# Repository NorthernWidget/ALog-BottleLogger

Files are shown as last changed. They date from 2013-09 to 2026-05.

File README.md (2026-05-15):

ALog-BottleLogger
=================

## Deprecation / update notice

The lovely ALog has a dear place in our hearts, but time flows by.

For our modern supported data loggers, see:
* [Project Margay](https://github.com/NorthernWidget-Skunkworks/Project-Margay): Small form factor ALog-like data logger, optimized for digital communications
* [Project Resnik](https://github.com/NorthernWidget-Skunkworks/Project-Resnik): Data logger for large installations, solar power, and telemetry

## ALog BottleLogger Basic Information

The ALog BottleLogger is an Arduino-based low-power field environmental data logging platform.

This repository contains hardware design files, centered around:
* Electronic schematics
* Circuit board layouts

In addition, the following are supplied, but are not always kept up-to-date in the main branch:
* Bill of materials (electronic components)
* Gerber files for circuit board production
* Pick-and-place files

## Layout Overview for End-Users

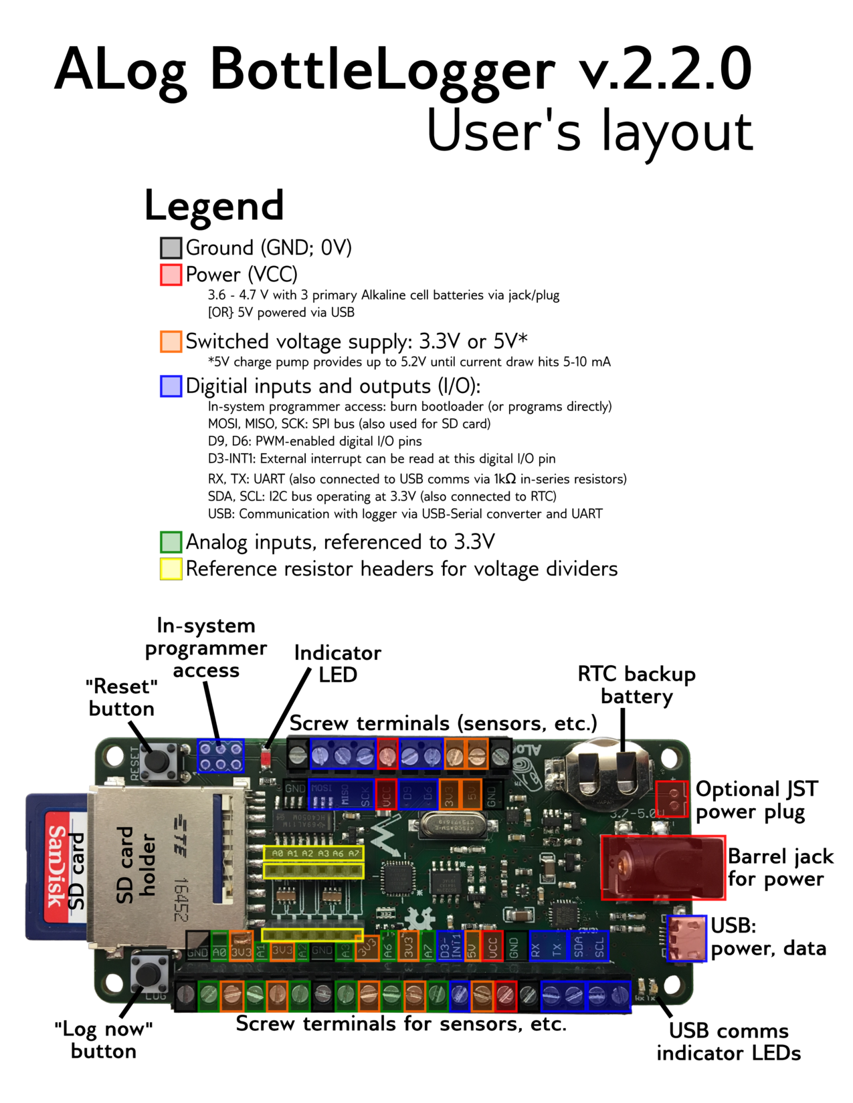
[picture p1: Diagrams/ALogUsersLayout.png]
Layout guide for end-users


<!--
![Major components](https://github.com/NorthernWidget/ALog-BottleLogger/blob/master/Diagrams/ALogComponents.png?raw=true)

## Significant components

<img alt="Major components" src="https://github.com/NorthernWidget/ALog-BottleLogger/blob/master/Diagrams/ALogComponents.png?raw=true" width="1000">

<img alt="Layout guide for end-users" src="https://github.com/NorthernWidget/ALog-BottleLogger/blob/master/Diagrams/ALogUsersLayout.png?raw=true" width="1000">
-->

## Citation

If you use this data logger in a publication, please cite:

**Wickert, A. D. (2014), [The ALog: Inexpensive, Open-Source, Automated Data Collection in the Field](https://doi.org/10.1890/0012-9623-95.2.68), *Bull. Ecol. Soc. Am.*, *95*(2), 68–78, doi:10.1890/0012-9623-95.2.68.**

**Wickert, A. D., C. T. Sandell, B. Schulz, and G.-H. C. Ng (2019), [Open-source Arduino-compatible data loggers designed for field research](https://doi.org/10.5194/hess-23-2065-2019), *Hydrol. Earth Syst. Sci.*, *23*, 2065–2076, doi:10.5194/hess-23-2065-2019.**

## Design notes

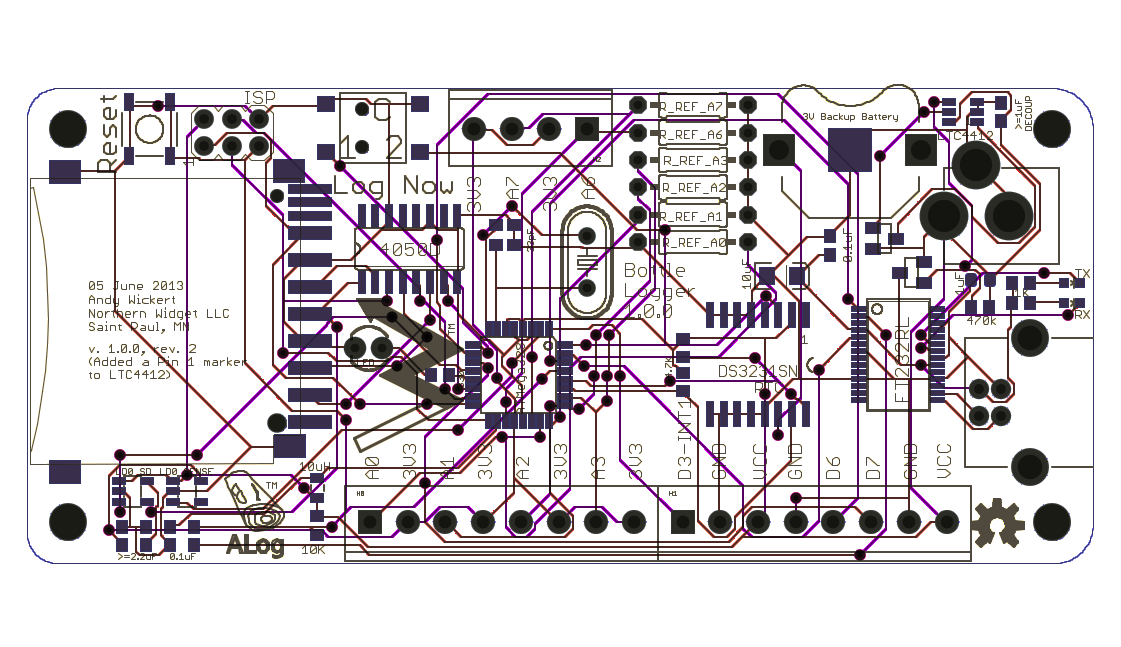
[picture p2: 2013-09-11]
Diagrams/Logger100/ALog_BottleLogger_100_rev2_white_background.png

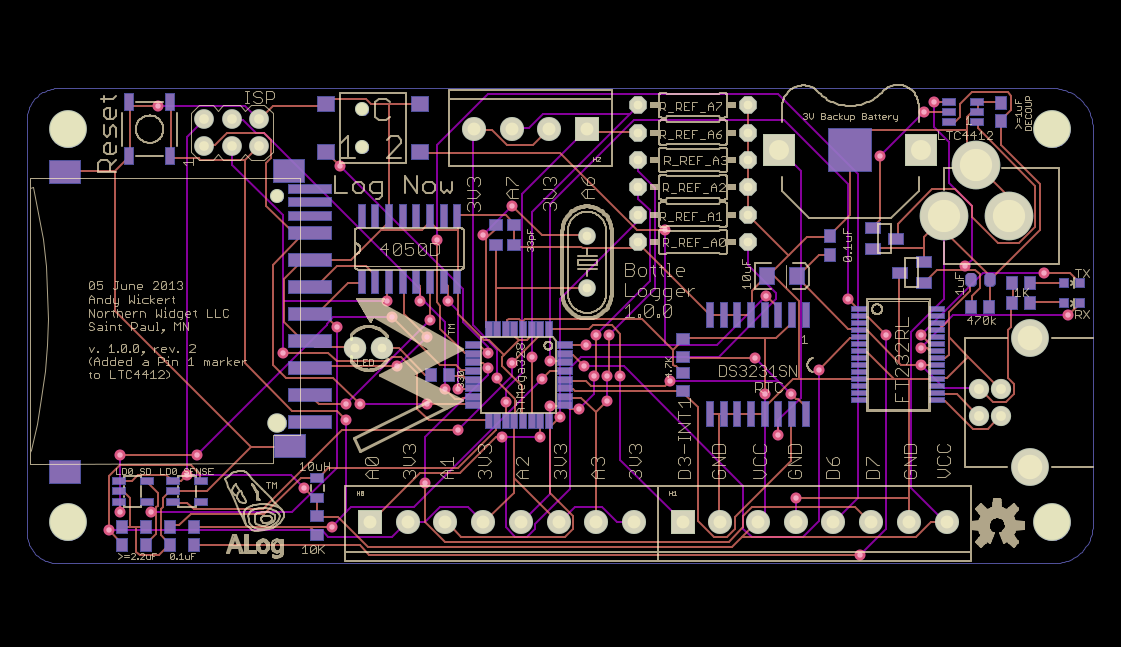
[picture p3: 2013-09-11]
Diagrams/Logger100/ALog_BottleLogger_100_rev2.png

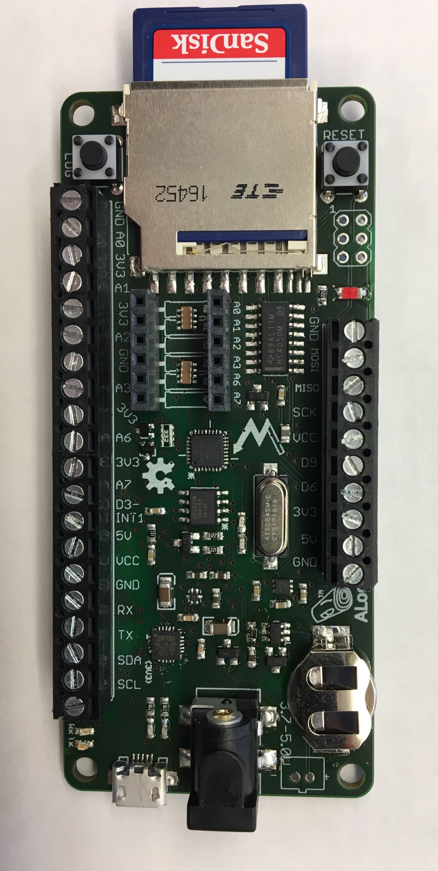
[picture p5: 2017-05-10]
Diagrams/ALog220.jpg

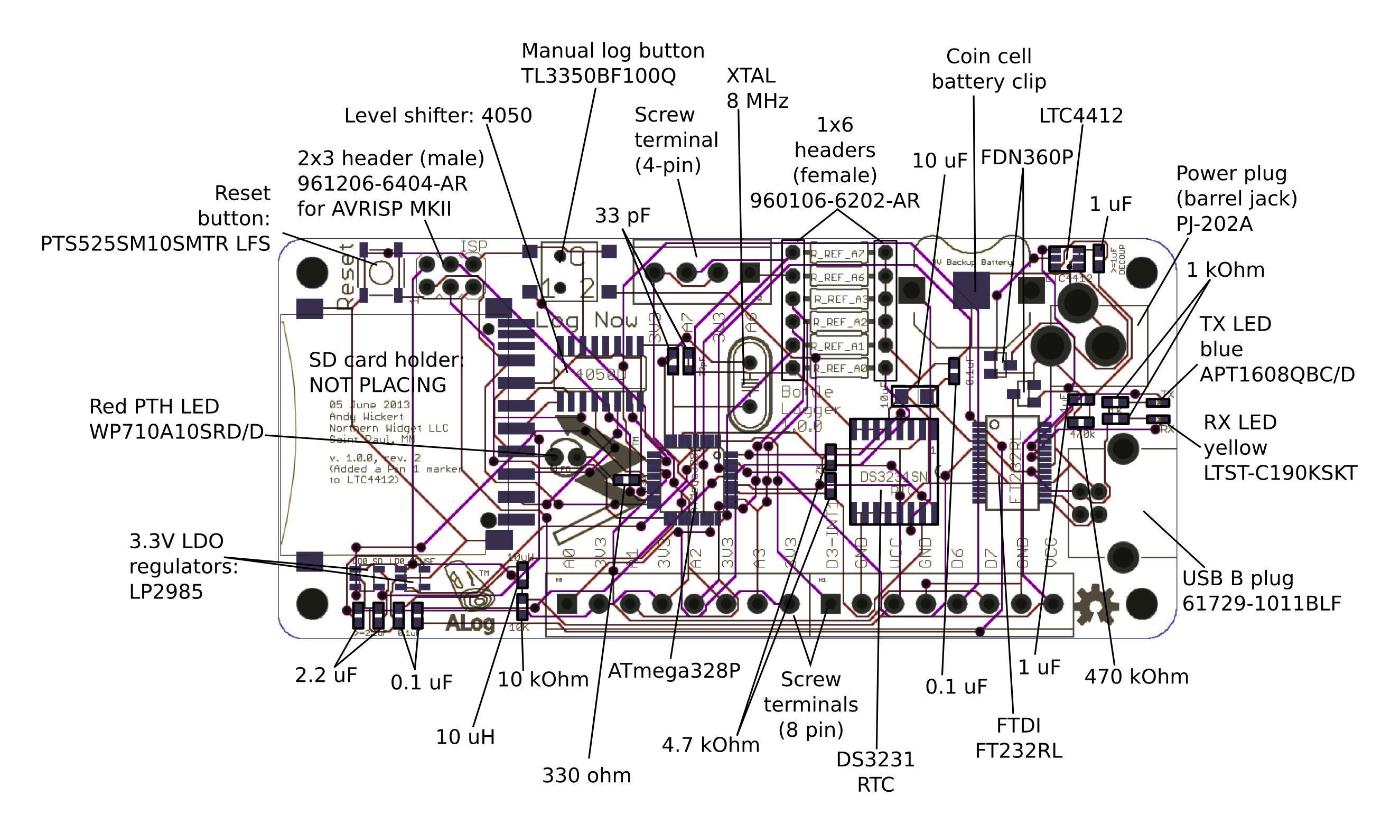
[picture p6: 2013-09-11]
Diagrams/Logger100/ALog_100_rev2_location_drawing.png

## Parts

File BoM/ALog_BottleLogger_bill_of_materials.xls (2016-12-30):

Manufacturer | Manufacturer Part Number | Part Description | Device Usage | Quantity
KEMET (VA) | C0603C105K8PACTU | CAP CER 1UF 10V X5R 0603 | DECOUPLING VCC and VCC/CLOCK BATT, RESET | 5
YAGEO (VA) | RC0603JR-07220RL | RES SMD 220 OHM 5% 1/10W 0603 | LED; CLOCK BACKUP BATTERY POWER SWITCHING | 3
ON SHORE TECHNOLOGY INC | OSTTE100104 | TERMINAL BLOCK 3.5MM 10POS PCB | SCREW TERMINAL - 10 | 3
TDK CORPORATION (VA) | CKCA43X7R1H103M100AA | CAP ARRAY 10000PF 50V X7R 1206 | ADC, SD/RTC, AND VCC DECOUPLING | 2
KEMET (VA) | C0603C330J5GACTU | CAP CER 33PF 50V NP0 0603 | XTAL CAPS | 2
Samtec | SSW-106-22-S-S | CONN HEADER FEMALE 6POS .1" GOLD | REFERENCE RESISTORS - 6 PIN | 2
NXP SEMICONDUCTORS (VA) | 2N7002PW,115 | MOSFET N-CH 60V 0.31A SOT323 | I2C LEVEL SHIFT | 2
FAIRCHILD SEMICONDUCTOR (VA) | FDN360P | MOSFET P-CH 30V 2A SSOT3 | HELP IN AUTOMATIC POWER SUPPLY SWITCHING | 2
YAGEO (VA) | RC0603JR-0727RL | RES SMD 27 OHM 5% 1/10W 0603 | USB DATA I/O | 2
Texas Instruments | TPS60150DRVR | IC REG SWTCHD CAP 5V 0.14A 6SON | 5V charge pump, 5.17 until about 10ma | 1
AMPHENOL FCI | 69192-406 | CONN HEADER VERT DUAL 6POS | AVRISP MKII | 1
TE CONNECTIVITY AMP (VA) | 2041021-4 | CONN SD CARD PUSH-PULL R/A SMD | SD CARD HOLDER | 1
CTS-FREQUENCY CONTROLS | ATS08A-E | CRYSTAL 8.0000MHZ 20PF T/H | MCU OSCILLATOR | 1
Bourns Inc. | CV201210-100K | FIXED IND 10UH 150MA 360 MOHM | LOW PASS FILTER TO ADC | 1
TEXAS INSTRUMENTS (VA) | CD74HC4050M96 | IC BUFFER HEX 1INPUT 16SOIC | 4050 LEVEL SHIFTER: SD | 1
LINEAR TECHNOLOGY (VA) | LTC4412ES6#TRMPBF | IC OR CTRLR SRC SELECT TSOT23-6 | AUTOMATIC POWER SUPPLY SWITCHING - MAIN CHIP | 1
LITE-ON INC (VA) | LTST-C190KSKT | LED YELLOW CLEAR 0603 SMD | RX LED | 1
CTS Resistor Products | 742C083102JP | RES ARRAY 4 RES 1K OHM 1206 | RES ARRAY 4 RES 1K OHM 603 | 1
CTS Resistor Products | 742C083332JP | RES ARRAY 4 RES 3.3K OHM 1206 | RES ARRAY 4 RES 3.3K OHM 603 | 1
STACKPOLE ELECTRONICS INC (VA) | RMCF0603FT470K | RES SMD 470K OHM 1% 1/10W 0603 | POWER SUPPLY SWITCHING | 1
AMPHENOL FCI | 61729-1011BLF | USB RCPT B-TYPE R/A FULL BACK | USB PLUG | 1
Microchip Technology | MIC5380-SSYFT-TR | IC REG LDO 3.3V 0.15A 6TMLF | Linear Voltage Regulator Fixed 2 Output 3.3V 150mA | 1
KEMET (VA) | C0603C104K4RACTU | CAP CER 0.1UF 16V X7R 0603 | DECOUPLING (FTDI VCCIO, 328P VCC) | 5
YAGEO (VA) | CC0603KRX5R6BB225 | CAP CER 2.2UF 10V X5R 0603 | LDO REGULATOR & VCC DECOUPLING | 3
TAIYO YUDEN (VA) | LMK316BJ106KL-T | CAP CER 10UF 10V X5R 1206 | USB DECOUPLING, AND BOOST CONVERTER | 2
TE CONNECTIVITY ALCOSWITCH | 1825910-6 | SWITCH TACTILE SPST-NO 0.05A 24V | RESET & LOG BUTTONS | 2
ENERGIZER BATTERY COMPANY | CR1220VP | BATTERY LITHIUM 3V COIN 12.5MM | COIN CELL: CLOCK BACKUP BATTERY | 1
Samsung Electro-Mechanics America, Inc. Samsung Electro-Mechanics America, Inc. | CL10A475MP5LNNC | CAP CER 4.7UF 10V X5R 0603 | CHARGE PUMP CAPACITOR | 1
CUI INC | PJ-202A | CONN POWER JACK 2.1MM PCB | POWER PLUG | 1
ATMEL | ATMEGA328P-MN | IC MCU 8BIT 32KB FLASH 32VQFN | MICROCONTROLLER CORE | 1
MAXIM INTEGRATED | DS3231MZ/V+ | IC RTC CLK/CALENDAR I2C 8-SOIC | REAL TIME CLOCK (RTC) | 1
FTDI | FT231XQ-T | IC USB SERIAL FULL UART 20QFN | FTDI USB | 1
Linear Technology | LT1461CIS8-3.3#PBF | IC VREF SERIES 3.3V 8SOIC | PRECISION 3.3V 100MA 0.08%, 12PPM/C | 1
KINGBRIGHT COMPANY LLC (VA) | APT1608QBC/D | LED BLUE CLEAR 0603 SMD | TX LED | 1
KINGBRIGHT COMPANY LLC | WP710A10SRD/D | LED RED DIFF 3MM ROUND T/H | FLASHING MESSAGES: INDICATOR LED | 1
STACKPOLE ELECTRONICS INC (VA) | RMCF0603JT10K0 | RES SMD 10K OHM 5% 1/10W 0603 | PULL UP FOR RESET | 1
KEYSTONE ELECTRONICS | 3001 | HOLDER BATTERY COIN 12MM DIA THM | CLOCK BACKUP BATTERY HOLDER | 1
DIODES INCORPORATED | BAT54C-7-F | DIODE ARRAY SCHOTTKY 30V SOT23-3 | DIODE ARRAY FOR BATT VS REGULATOR CLOCK POWER | 2
TDK CORPORATION (VA) | C1608NP01H470J080AA | CAP CER 47PF 50V NP0 0603 | USB-SERIAL | 0
Murata Electronics North America | LQH32PN4R7NN0L | ED IND 4.7UH 1A 180 MOHM SMD | 4.7UH INDUCTOR FOR BOOST CONVERTER | 0
Texas Instruments | TPS61222DCKR | IC REG BOOST 5V 0.2A SYNC SC70-6 | 3.3 TO 5V BOOST CONVERTER | 0
TEXAS INSTRUMENTS (VA) | MIC5305-3.3YD5-TR | IC REG LDO 3.3V 0.15A SOT23-5 | Linear Voltage Regulator IC Positive Fixed Output 3.3V 150mA | 0
STACKPOLE ELECTRONICS INC (VA) | RMCF0603FT1K00 | RES SMD 1K OHM 1% 1/10W 0603 | RX/TX RESISTORS | 0
YAGEO (VA) | RC0603JR-073KL | RES SMD 3K OHM 5% 1/10W 0603 | RTC PULL-UPS | 0
C&K COMPONENTS | PVA1 OA H4 1.2N V2 | SWITCH PUSH DPST-NO 0.1A 32V | MANUAL LOG BUTTON ("LOG NOW") | 0
Torex Semiconductor Ltd | XC9140A501MR-G | IC REG BST 5V 295MA SYNC SOT-25 | 3.3 TO 5V BOOST CONVERTER | 0
ON SHORE TECHNOLOGY INC | OSTTE040104 | TERMINAL BLOCK 3.5MM 4POS PCB | SCREW TERMINAL - 4 | 0
ON SHORE TECHNOLOGY INC | OSTTE080104 | TERMINAL BLOCK 3.5MM 8POS PCB | SCREW TERMINAL - 8 | 0
JST Sales America Inc. | B2B-XH-A(LF)(SN) |  | 2 Positions Header, Shrouded Connector 0.098" (2.50mm) Through Hole Tin | 1

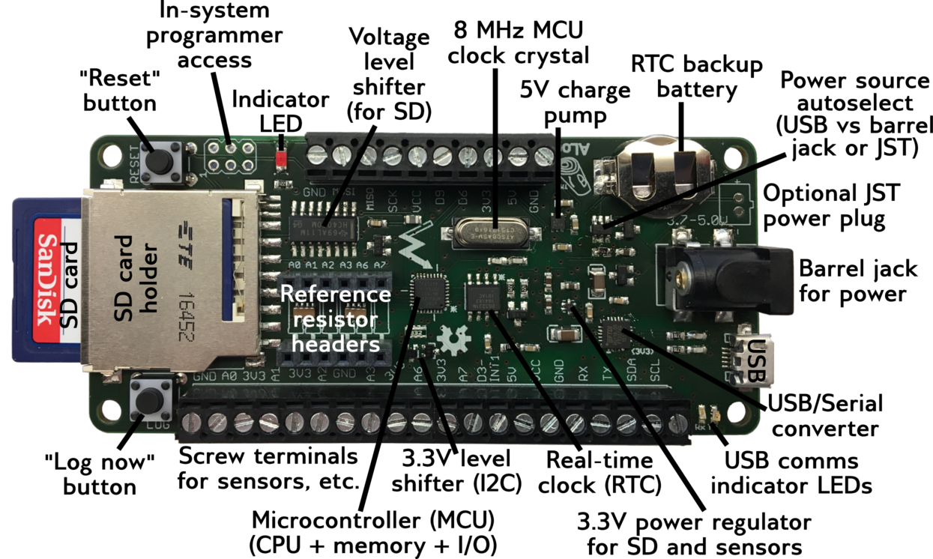
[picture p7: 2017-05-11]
Diagrams/ALogComponents.png

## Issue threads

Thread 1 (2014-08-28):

Formatting SD card makes it fail after a certain number of writes?

awickert, 2014-08-28:
Nick Evans is testing this.

See note at:
http://forum.arduino.cc/index.php?topic=164047.0

awickert, 2016-11-23:
Nick insists that this happened to him at random with his whole batch, but (1) it hasn't been reproduced by anyone else, anywhere else, and (2) the current logger version has seen a world of updates. So insofar as it did exist, it probably is gone and hasn't come up in any testing.

Closed 2016-11-23.

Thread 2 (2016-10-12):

Use watchdog timer to reset logger if it freezes.

awickert, 2016-10-12:
See: http://www.megunolink.com/articles/how-to-detect-lockups-using-the-arduino-watchdog/

Big question: how to keep the watchdog from resetting the logger while it is asleep? Do we wake the logger every second to tell the watchdog to turn off? Every 10 seconds? But WDT is 8 seconds max... And how to keep watchdog wakeup and RTC wakeup (and logging) from clashing?

Closed 2016-10-18.

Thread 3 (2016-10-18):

change out level shifter and replace 3.3V regulators

superchap123, 2016-10-18:
Current level shifter has unused pins, could switch to this:  MC74HC125ADGOS-ND

Could replace two 3.3V regulators with one part: 576-3453-1-ND

awickert, 2016-11-23:
Kept current level shifter -- common, inexpensive component (CMOS 4050)

Replaced 3V3 with this amazingly tiny and nice regulator!

Closed 2016-11-23.

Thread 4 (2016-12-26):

Potential power source issue from precision 3.3V regulator

awickert, 2016-12-26:
System did not fully boot with too many sensors (esp. RH) attached. Potential issues include:
* Not-fully-powered-up I2C sensors will override I2C clock signal and inhibit boot-up
* Other sensors also somehow prevent boot-up; is this because of an issue with this particular board, or more general? I don't understand it.

The precision 3.3V regulator was also showing voltages of up to 3.6V, and voltages that changed with the applied load. Again, possibly an issue with this particular board, or more general? So far, @superchap123 has not been able to reproduce it.

awickert, 2016-12-30:
We have reproduced the problem, and it is related to the charge pump, which causes the precision 3V3 to drop. Tests:

* Check if this happens with a non-precision 3V3
* Check how this affects VCC (power supply had oscillations and an overall voltage drop; batteries had no oscillations, but I can't remember if the voltage dropped)
* Try adding a LC filter to the power input to the charge pump (VCC to charge pump) to see if this fixes the issue. (This is a different part, but similar concept: https://www.maximintegrated.com/en/app-notes/index.mvp/id/2027)
* Maybe see if there is something related to the full-power mode vs. the low-power mode in which the charge pump just adds small pulses of energy to the system, intermittently.

awickert, 2017-01-01:
[NOTE: text below my bullet points in the above comment was written by @superchap123 following his text messages]

## Conclusions
* The ALog BottleLogger will just use a coarser-precision LDO regulator. Perfect for ratiometric measurements, and has much less drop when load is applied. Manual measurement of this voltage under load will be added to the EEPROM, and will be read when non-ratiometric measurements must be made.
* A future ARM-core logger will use a precision voltage reference, but that does not power anything. Power will be supplied by a separate 3V3 LDO regulator, whose voltage will be measured by a precision-resistor voltage divider. If ratiometric measurements are required, this measured voltage may be used as a basis, or a SPDT MOSFET could allow the VREF to be switched between the precision RRef for high-precision measurements and the LDO for higher-load ratiometric measurements.

### Thoughts
* Now that I type this out, we could institute this precision 3V3 with a MOSFET on the current logger board, should we choose to do so; this really makes more sense than sacrificing an analog pin to measure the internal 3V3, and this switch would be controlled by each sensor function in the library. We would lose a digital pin to this, though, and the ALog BottleLogger's main benefit of being simple and lightweight would be somewhat sacrificed. So pros and cons...
* If we're really worried about analog channels, we could just add an external ADC, and define its pins as "AE0, AE1, ..." for Analog External, for example. This could be generally useful; should talk with @s-hicks2 and @aufdenkampe about their choice of external ADC; would be excellent if this could be I2C- or SPI-controlled (I2C better for using fewer pins).

*Many of the above notes are inspired by this general issue, but could be spun off to their own issues / planned enhancements*

**I will close this thread once we implement a specific solution for the ALog BottleLogger.**

awickert, 2017-01-26:
We are using the small 3V3 LDO regulator that Chad found for everything, and have added functions to save and read the ARef. These can be eventually integrated into one of our "examples".

```
void save_Aref(float _V){
  /**
   * @brief
   * Saves a float as the reference voltage for the ADC ("Vref") to the EEPROM
   *
   * @details
   * ADC == analog-digital comparator
   * EEPROM = permanent memory (persists after shutdown)
   * See: https://www.arduino.cc/en/Reference/EEPROMPut
   *
   * This function is only called rarely, as this value is typically measured
   * only once.
   *
   * @param _V reference voltage, ideally measured under load [V]
   *
   * Example:
   * ```
   * // Measuring 3.297V with a calibrated multimeter between 3V3 and GND
   * // Then:
   * logger.saveAref(3.297);
   * ```
   *
   */
   EEPROM.put(4, _V);
}

float read_Aref(){
  /**
   * @brief
   * Read the analog (ADC) sensor reference voltage from EEPROM, return float.
   *
   * @details
   * ADC == analog-digital comparator
   * EEPROM = permanent memory (persists after shutdown)
   * See: https://www.arduino.cc/en/Reference/EEPROMGet
   *
   * Example:
   * ```
   * float Vref;
   * Vref = logger.readAref();
   * ```
   *
   */
  float _V;
  EEPROM.get(4, _V);
  return _V;
}
```

Closed 2017-01-26.

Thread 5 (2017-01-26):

Convert components to SMD

awickert, 2017-01-26:
* Xtal: http://www.digikey.com/products/en/crystals-oscillators-resonators/crystals/171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
* LED (for messages)
* LOG and RESET buttons

Less sure if these work with pick and place:
* 3x2 ISP header
* 2x 1x6 Rref headers (reflow temperature?)
* JST connector (like Arduino Pro)
* Barrel jack

Keeping these through-hole:
* Screw terminals
* coin cell holder (lots of pressure)
* USB B (we pull hard on it... but should think about the option.)

awickert, 2017-03-11:
Xtal and LED are done.

awickert, 2017-03-30:
In branch https://github.com/NorthernWidget/ALog-BottleLogger/tree/smd:

**YES**
* Barrel jack done
* USB done and replaced by mini-B
* Considering SMD 1x6, but they are getting in the way of the labels
* Coin cell holder

**NO**
* 3x2 ISP header is a no; we'll just use pogo pins or a tensioned header to program (no more soldering)
* Screw terminals too expensive -- no

**MAYBE**
* JST staying through-hole; @superchap123 concerned about strength. Here are the DigiKey parts if we don't care about that: https://www.digikey.com/products/en/connectors-interconnects/rectangular-connectors-headers-male-pins/314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

awickert, 2017-04-11:
In branch https://github.com/NorthernWidget/ALog-BottleLogger/tree/smd:

**YES**
* USB done and replaced by mini-B (and updated by @superchap123)
* ~~Considering SMD 1x6, but they are getting in the way of the labels~~ **Too expensive**

**NO**
* JST staying through-hole, via intertia and not really using it anyway, plus all the good reasons above.
* RRef header: no, see "SMD 1x6" above. These are the same thing, and their dual inclusion was a mistake.

So... all decided!

Closed 2017-04-11.

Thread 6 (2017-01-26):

Replace the automatic power supply switching chip with cheaper solution

awickert, 2017-01-26:
Current chip (LTC4412) and its peripherals are among the more expensive components on the board -- in particular, the LTC4412 is.

awickert, 2017-03-11:
After discussing with Chad, this is not worth fixing: the 4412 has its advantages, and is well-integrated into the design.

Closed 2017-03-11.

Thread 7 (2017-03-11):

I2C causing voltage short between 3V3 and VCC

awickert, 2017-03-11:
This is from how I implemented Gerard's clock trick for low-power via VCC on the backup battery line; VCC and 3V3 are connected together to SDA and SCL!

awickert, 2017-03-11:
Cut the traces to VCC -- and the trace between the pads (left them jumpered for a while and didn't know why the loggers weren't working -- oops!). They now work well.

We used 3V3 to match many sensors, but the clock (DS3231) is tolerant to up to 5.5V on SDA and SCL regardless of its VIN.

Closed 2017-03-11.

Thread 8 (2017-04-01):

I2C level shifting

awickert, 2017-04-01:
I2C level shifting was an issue; our plan (which we have completed -- this bug report is a note) is to restore the MOSFET-based level shifter and to connect the 3V3(!!!) pins off-board.

I have done this.
Not closing this yet because:
* @superchap123  hasn't yet reviewed
* We need to check into rumor that gate-source threshold must be > source - drain difference (don't think so from our tests, but want to double-check)
* We may want to add a (3V3) to the Silk layer on SDA and SCL.

awickert, 2017-04-01:
OK, Silk note added. Just review by @superchap123  needed.

superchap123, 2017-04-04:
@awickert I am reviewing the SMD branch file and the MOSFETS have not been restored.  Do you need to push a local copy yet or does this need to get fixed?

awickert, 2017-04-11:
@superchap123 We figured this out! And ordered the replacement boards (thanks!).

Closed 2017-04-11.

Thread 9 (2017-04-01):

2x 3V3 needed?

awickert, 2017-04-01:
We currently have

* 3V3 1
** RTC
** SD card
** I2C pull-ups
* 3V3 2
** Analog sensor power
** Any other external sensor, etc. power

Do we really need this? Note:
* Will be on at around the same time
* Sensors can use the external power, but (if I2C) be pulled up to 3V3 from the internal power.

Note also:
* This might not be a problem having 2 in the same chip (like what Chad has found) -- certainly within I2C tolerance even if both sides don't use the same 3V3 regulator (I'm guessing they tap into the same one)
* We already have a reel of these chips...

Tentative conclusion:
* Keep separate, do nothing; hold the status quo because no real gains or losses.

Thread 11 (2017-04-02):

Test external UART and how it may interfere with Serial communications

awickert, 2017-04-02:
Can we still send / receive from computer OK?

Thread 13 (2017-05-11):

Update micro-USB footprint

awickert, 2017-05-11:
* Holes for strain relief (suggested by @pmarchetto); this will also help component stay in place, and will remain compatible with USB ports that lack feet to go in the holes
* Suggest lengthening solder pads to make it easier to fix jumpers during manufacturing

awickert, 2017-05-11:
I'd suggest basing the design off of the following Sparkfun footprint, provided you can find the right part:
USB-B-MICRO-SMD_V03

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

superchap123, 2017-12-04:
Lengthened pads a while back, done.

Closed 2017-12-04.

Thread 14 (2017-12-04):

Vampire resistors

superchap123, 2017-12-04:
Use comparator with mosphet to reduce current.  Attach voltage dividers to external power to eliminate divider current.

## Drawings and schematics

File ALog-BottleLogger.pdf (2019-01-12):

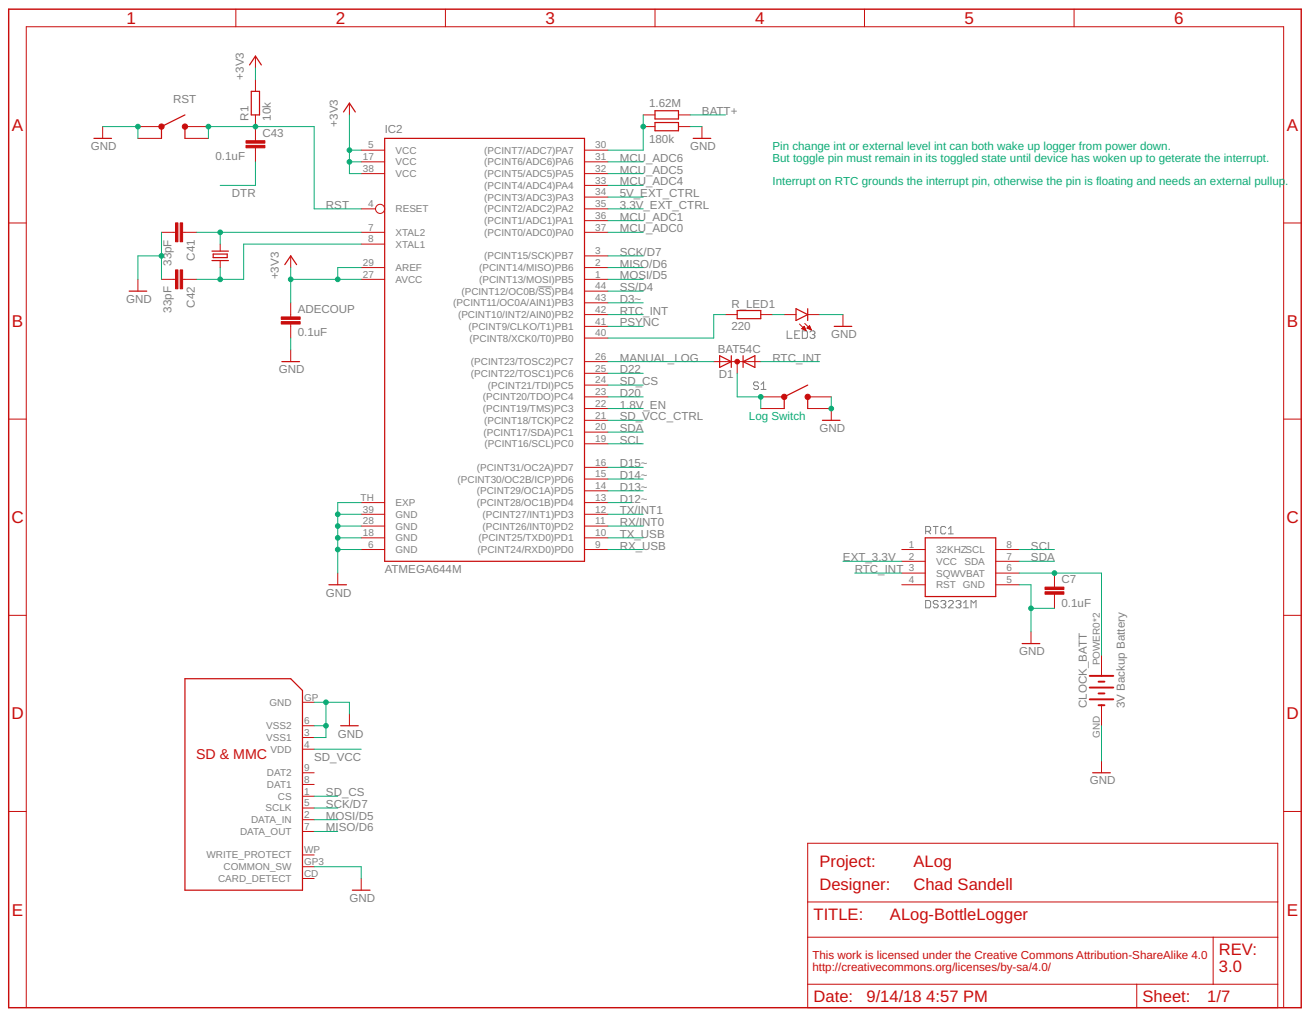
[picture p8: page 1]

Pin change int or external level int can both wake up logger from power down. But toggle pin must remain in its toggled state until device has woken up to geterate the interrupt.

Interrupt on RTC grounds the interrupt pin, otherwise the pin is floating and needs an external pullup.

This work is licensed under the Creative Commons Attribution-ShareAlike 4.0 http://creativecommons.org/licenses/by-sa/4.0/ | REV:

Date: 9/14/18 4:57 PM | Sheet: 1/7

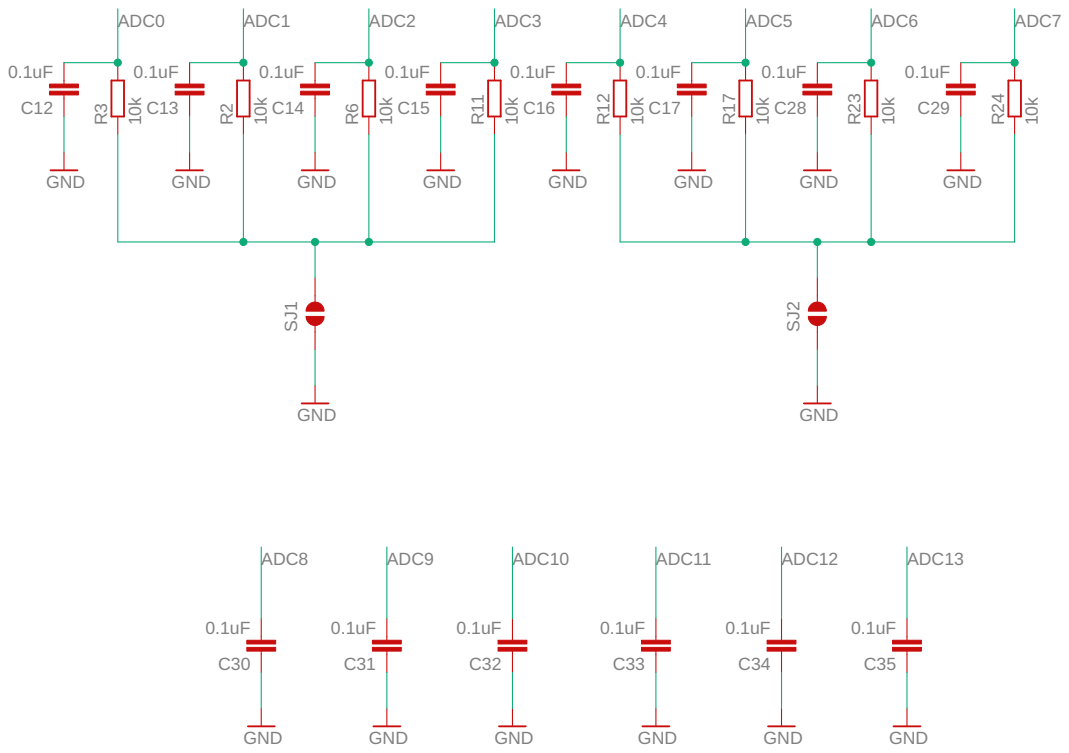
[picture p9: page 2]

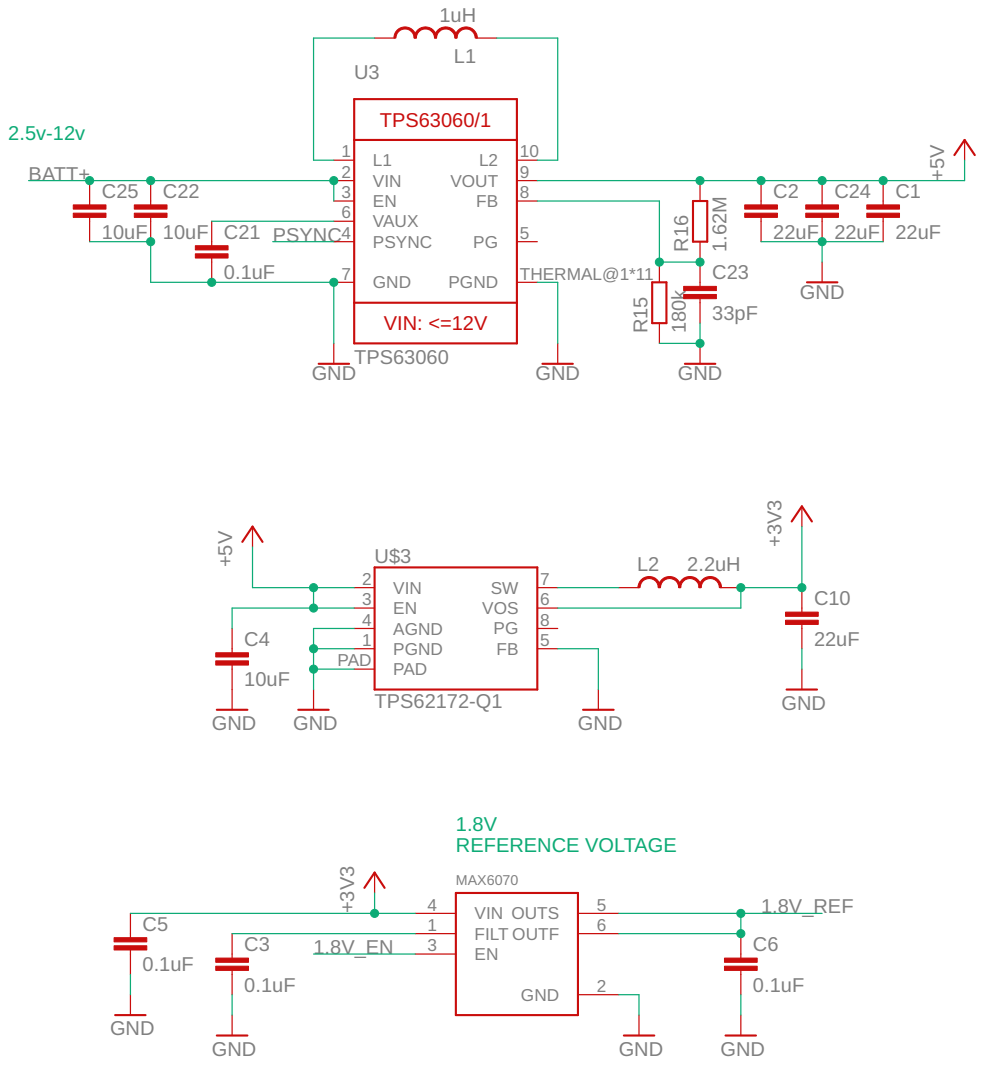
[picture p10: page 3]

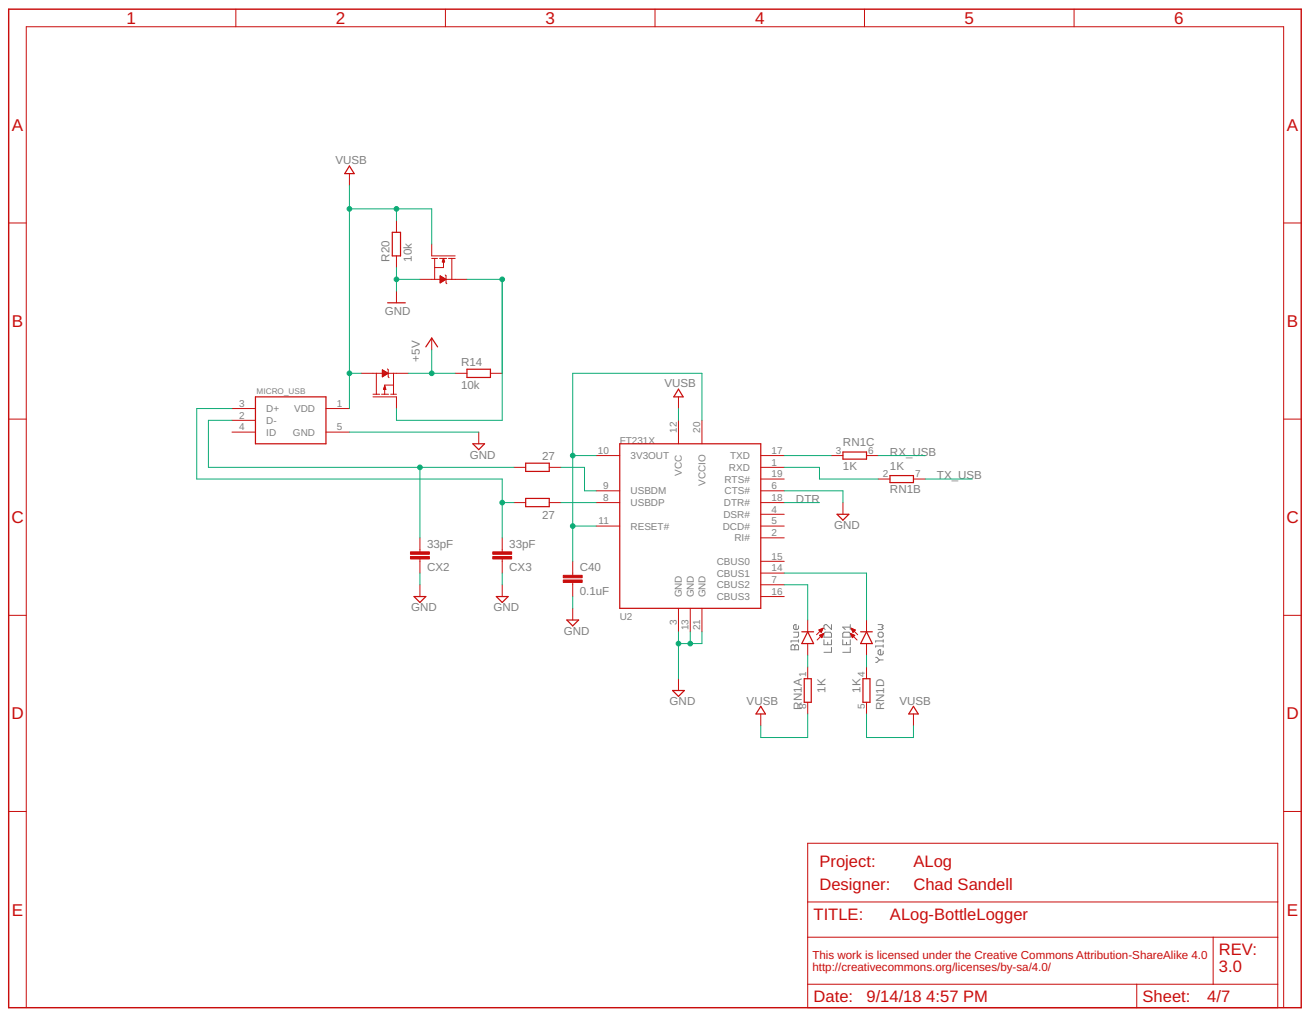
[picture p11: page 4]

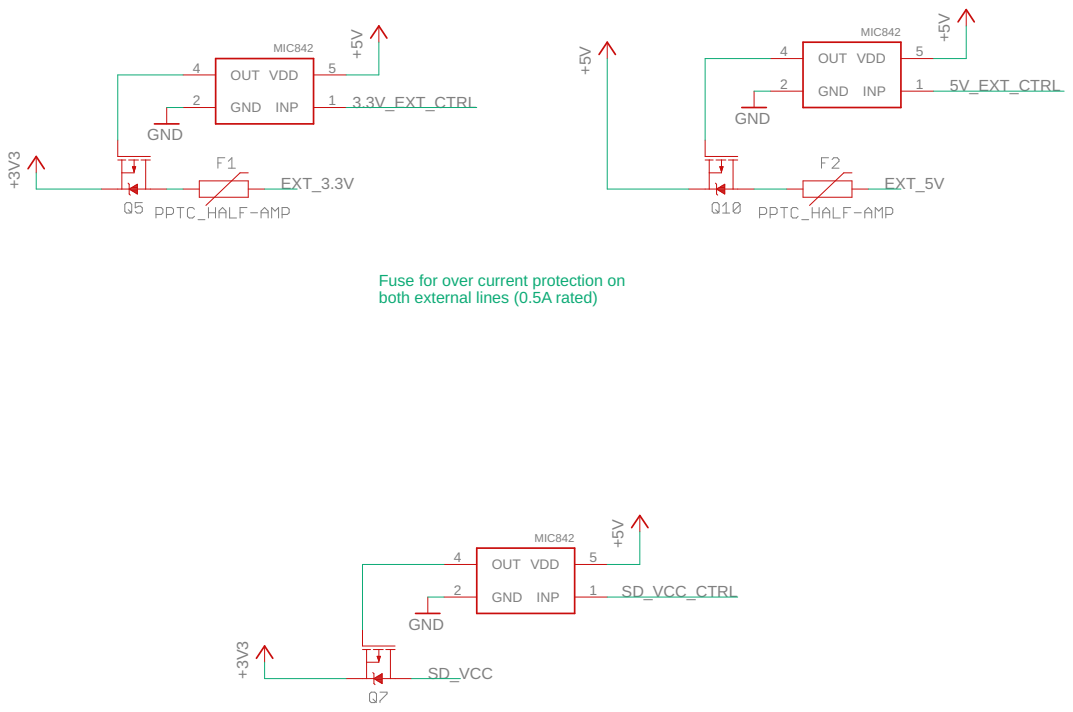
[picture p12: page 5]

Fuse for over current protection on
both external lines (0.5A rated)

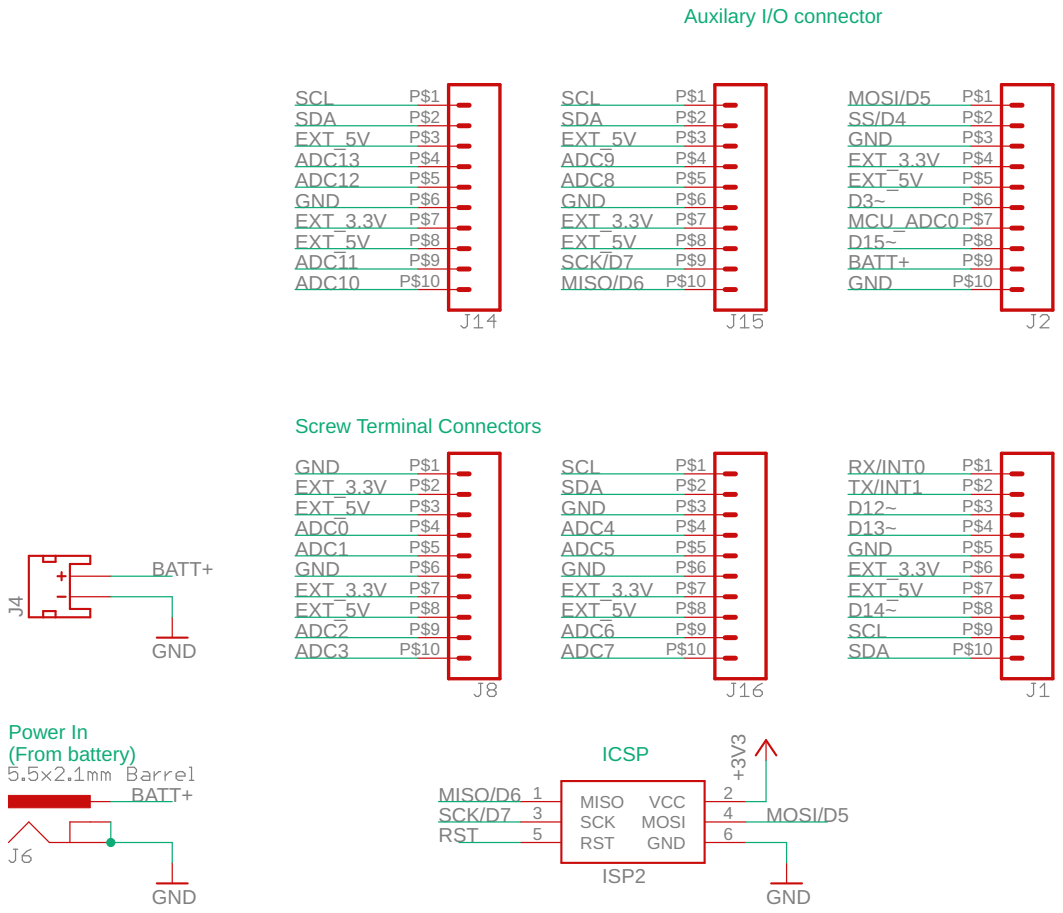
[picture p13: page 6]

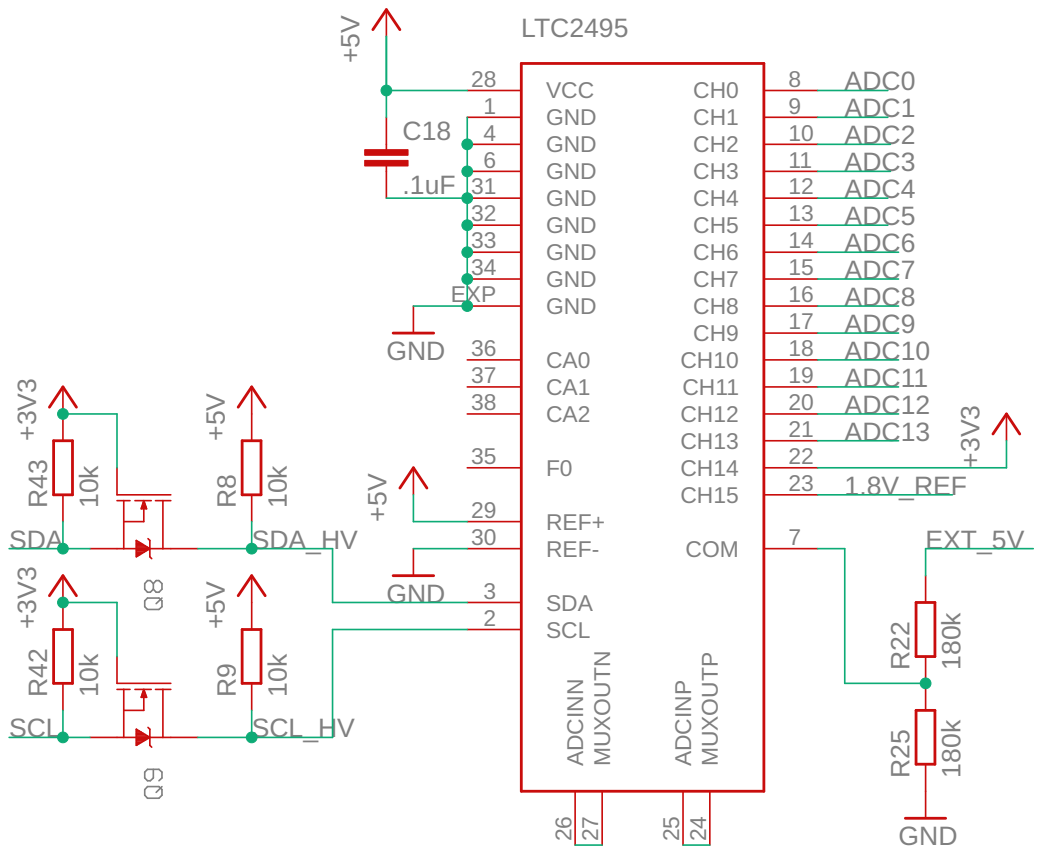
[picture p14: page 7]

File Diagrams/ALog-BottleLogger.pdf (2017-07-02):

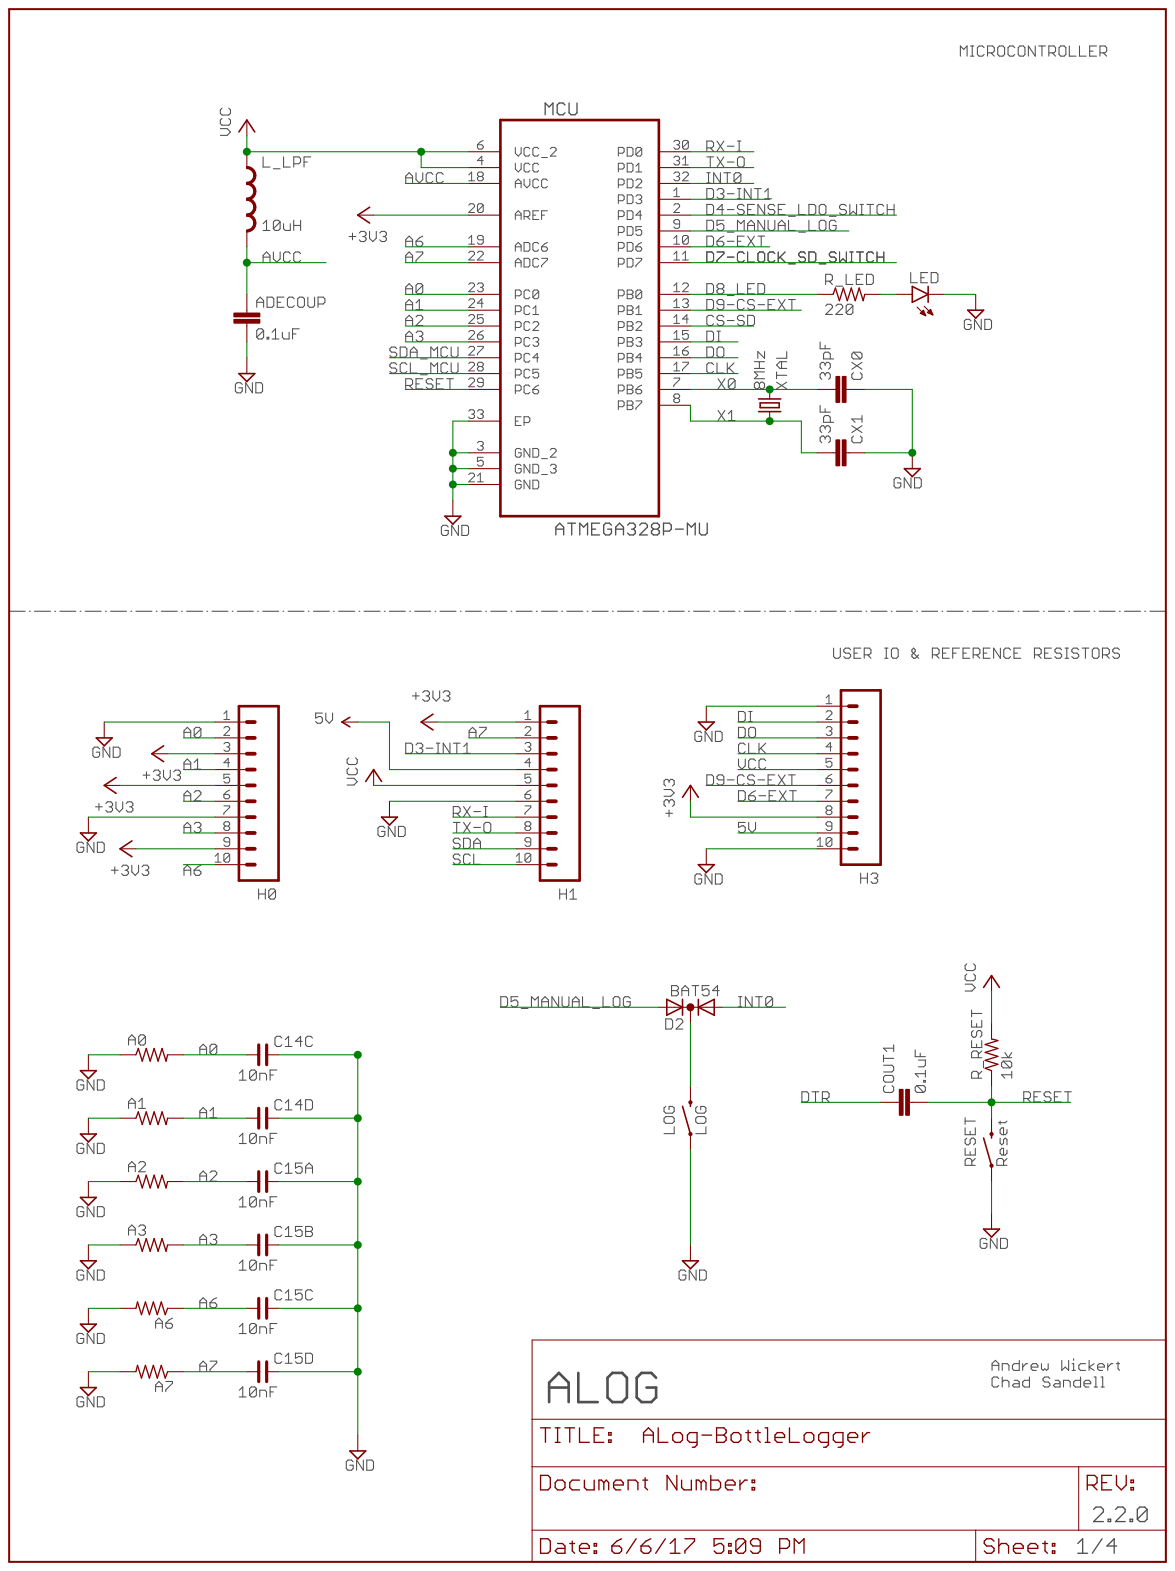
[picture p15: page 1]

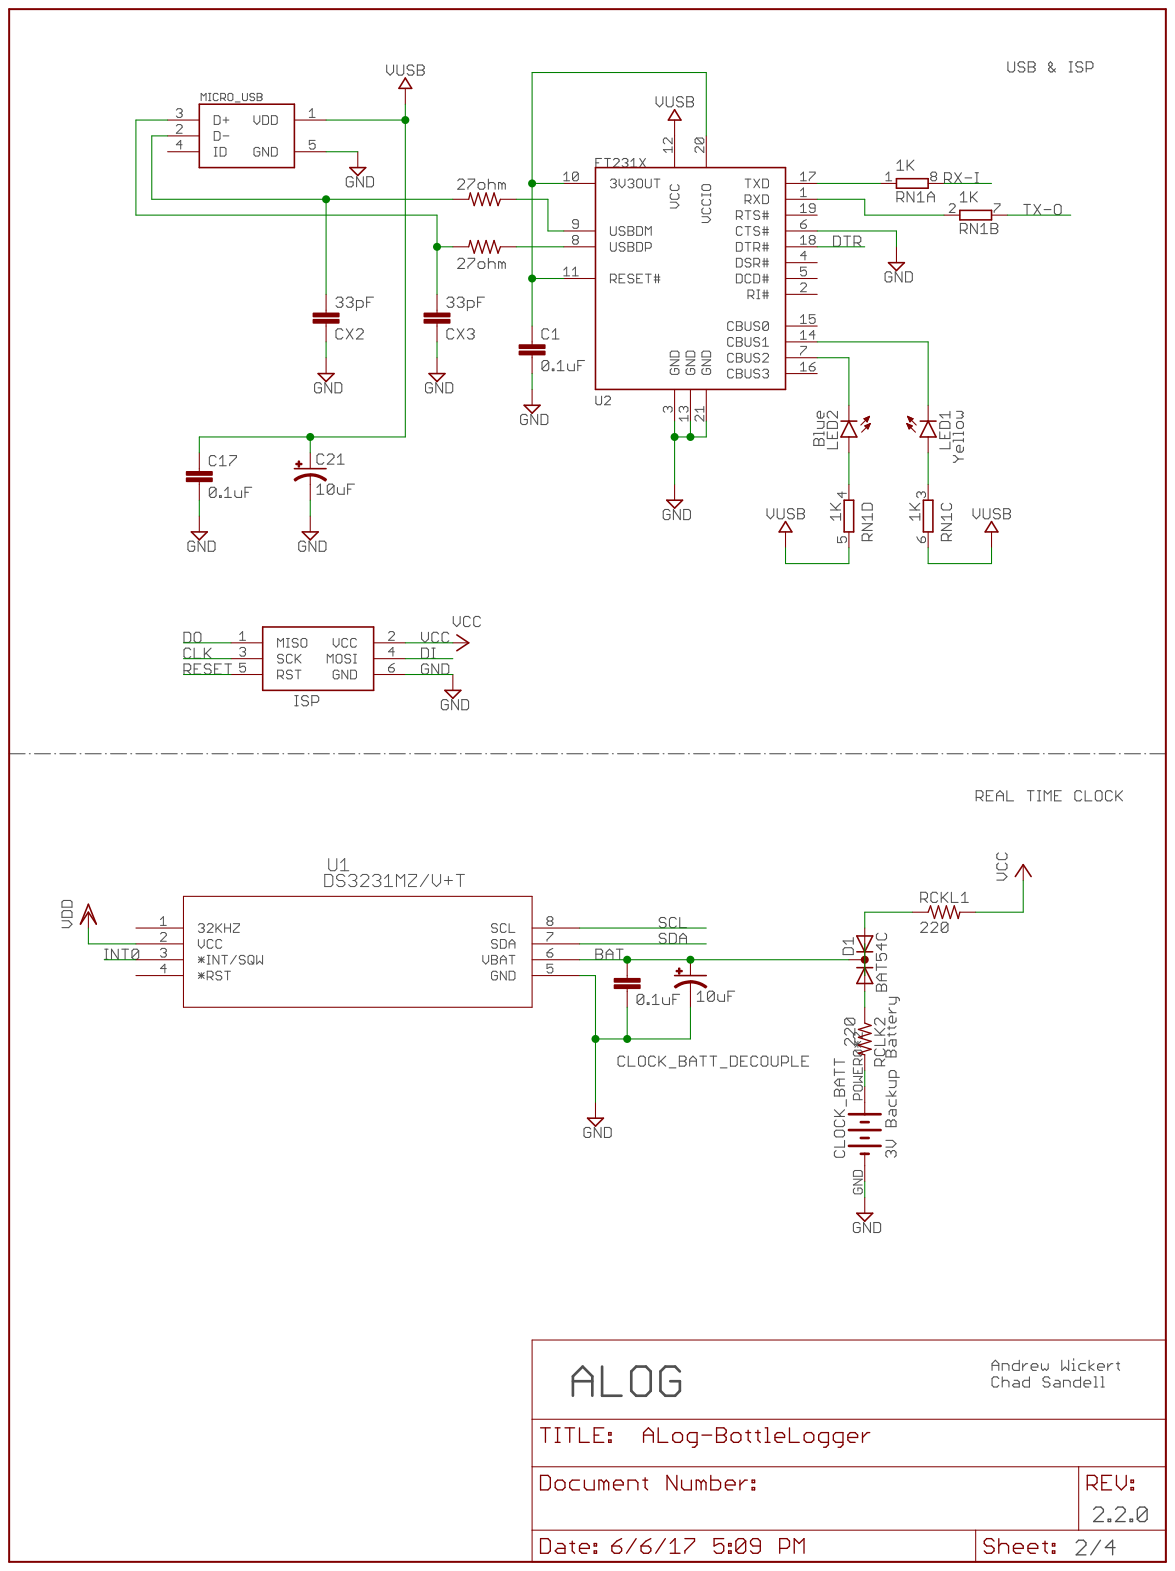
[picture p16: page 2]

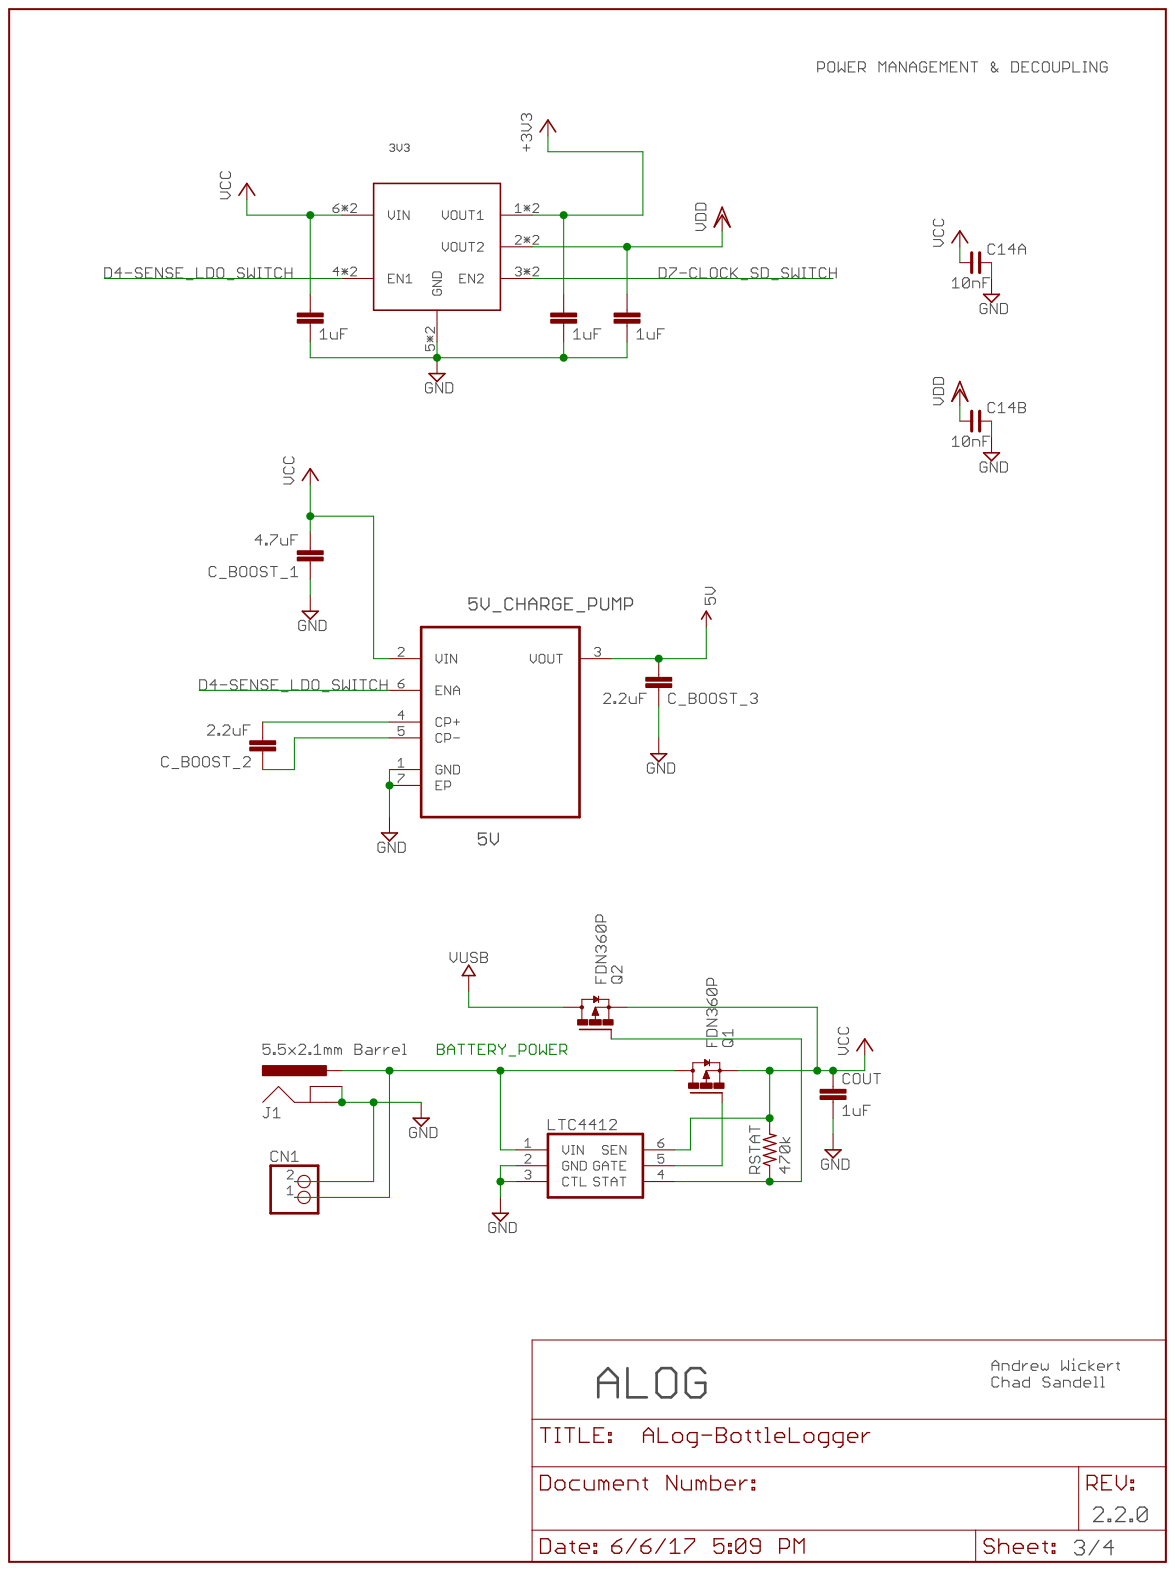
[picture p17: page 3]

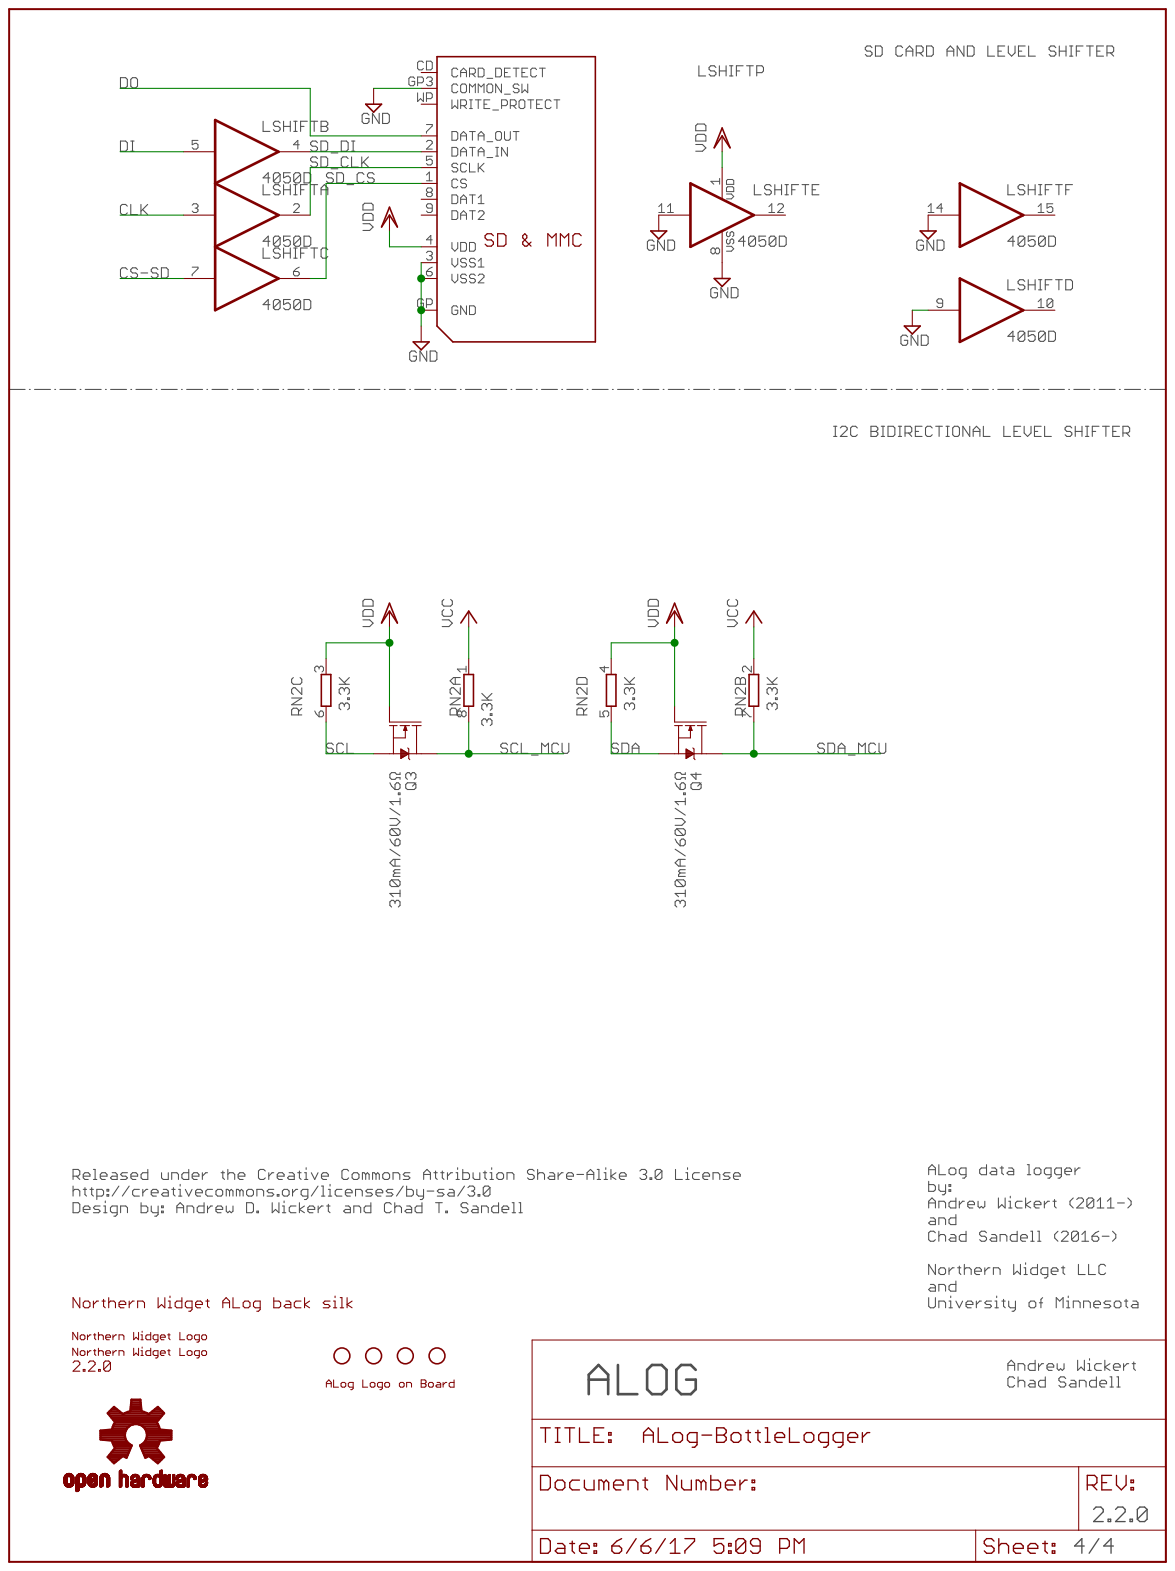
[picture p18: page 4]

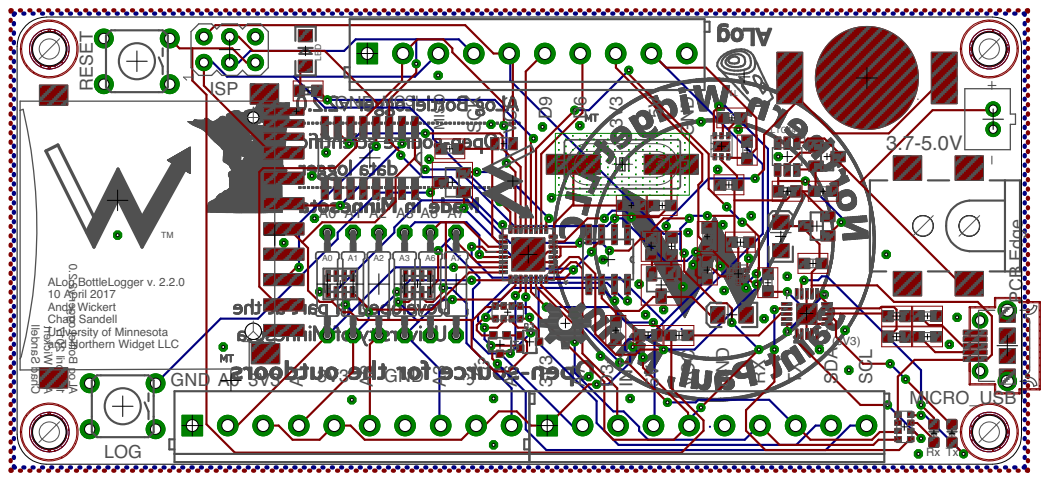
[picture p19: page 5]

ALog BottleLogger v2.2.0 10 April 2017 Andy Wickert Chad Sandell A13V3 A2GND A3GND D3- INT1 5VGND VCC ALog BottleLogger v. 2.2.0 10 April 2017 Andy Wickert Chad Sandell University of Minnesota and Northern Widget LLC A63V3 A73V3 A0 3V3 TM MT 1 RXTX MOSI SCKD9 SDA SCL VCC5V 3V3 GND TM Rx Tx A0 A1 A2 A3 A6 A7 GND MISO D6 3.7-5.0V (3V3) A0 A1 A2 A3 A6 A7 RESET LOG * * PCB Edge ISP LED LTC4412 MICRO_USB

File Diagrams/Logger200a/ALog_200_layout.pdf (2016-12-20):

# ALog BottleLogger v2.0.0

GND; INT1; VCC; MOSI; SCK; SDA; SCL; MISO; ISP; LED; RESET; LOG; 3.3_SENSE; 3V Backup Battery; FDN360P; LTC4412; BAT54C; BAT54; 27ohm 27ohm; Scale: 2:1

ALog BottleLogger v. 2.0
31 October 2016
Andy Wickert
Chad Sandell
University of Minnesota
and Northern Widget LLC







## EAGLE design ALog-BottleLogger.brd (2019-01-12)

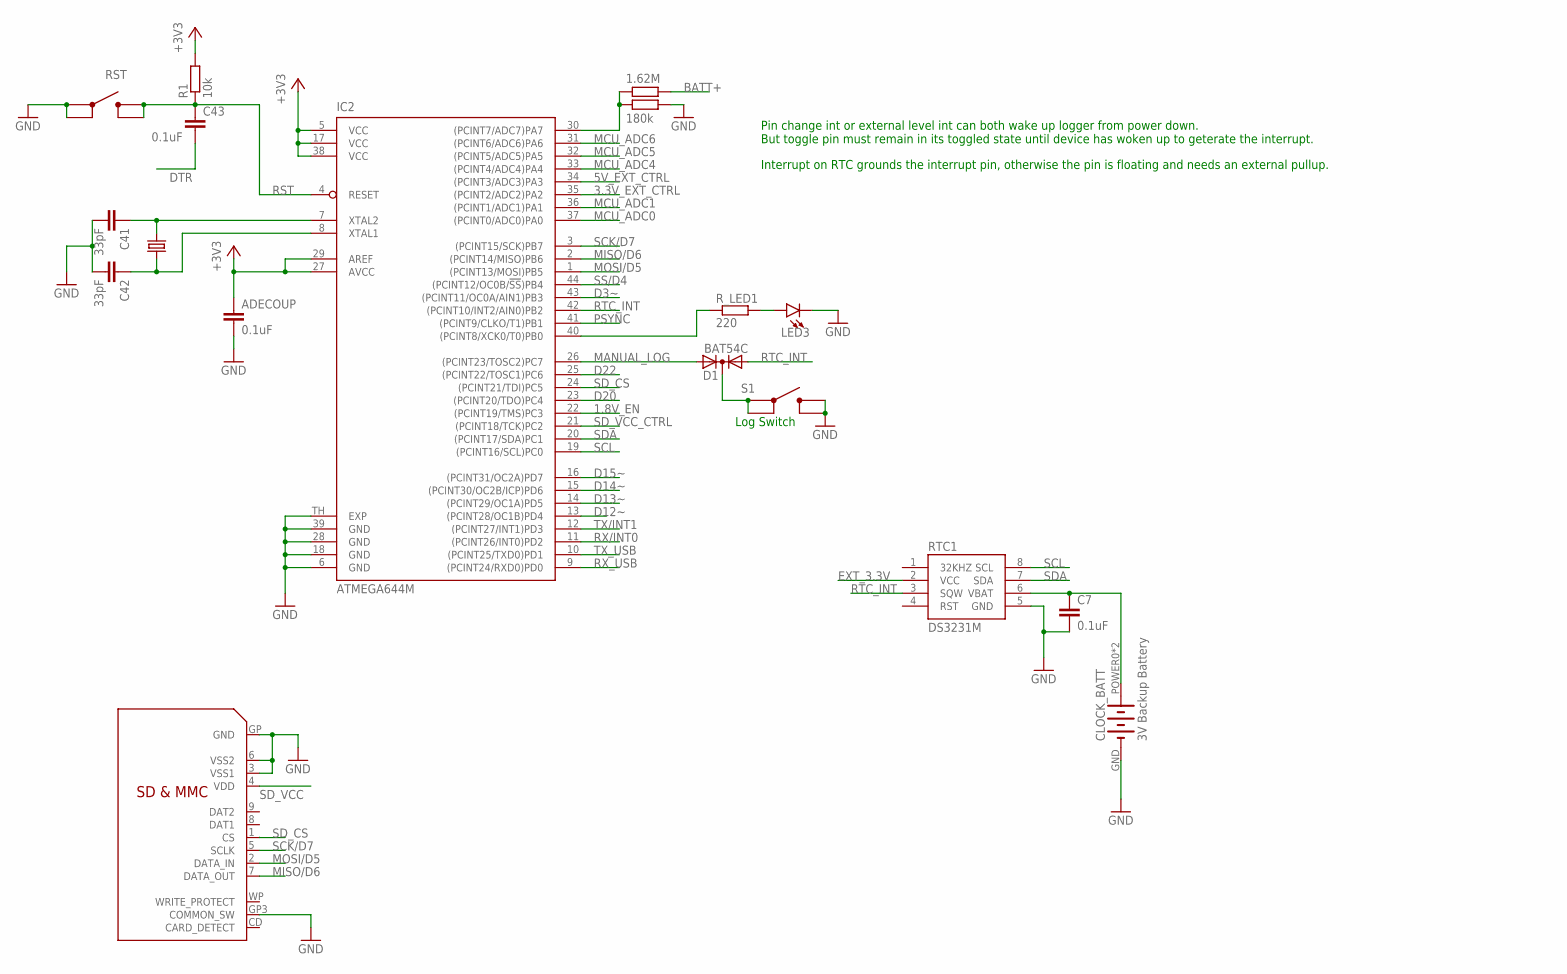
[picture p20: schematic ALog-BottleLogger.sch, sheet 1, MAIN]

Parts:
ADECOUP: 0.1uF; C0603
C7, C43: 0.1uF; C0603
C41, C42: 33pF; C0603
CLOCK_BATT: 3V Backup Battery; LINX_BAT-HLD-012-SMT
D1: BAT54C; SOT23C
IC2: ATMEGA644M; MLF44-TH
LED3: LED1206; LED-1206
Q3: CRYSTALHC49UP; HC49UP
R1: 10k; R0603
R18: 1.62M; R0603
R19: 180k; R0603
RTC1: DS3231M; SO08
R_LED1: 220; R0603
S1: SWITCHC&K_400GF; SWITCH_4.2X3.2
SD: SDMMC06132; 06132
U$4: SWITCHC&K_400GF; SWITCH_4.2X3.2

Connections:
1.8V_EN: IC2.22 ((PCINT19/TMS)PC3); also elsewhere on the board
3.3V_EXT_CTRL: IC2.35 ((PCINT2/ADC2)PA2); also elsewhere on the board
5V_EXT_CTRL: IC2.34 ((PCINT3/ADC3)PA3); also elsewhere on the board
+3V3: ADECOUP.1, IC2.5 (VCC), IC2.17 (VCC), IC2.27 (AVCC), IC2.29 (AREF), IC2.38 (VCC), R1.2; also elsewhere on the board
ADC16: IC2.30 ((PCINT7/ADC7)PA7), R18.1, R19.1
BATT+: R18.2; also elsewhere on the board
D3~: IC2.43 ((PCINT11/OC0A/AIN1)PB3); also elsewhere on the board
D12~: IC2.13 ((PCINT28/OC1B)PD4); also elsewhere on the board
D13~: IC2.14 ((PCINT29/OC1A)PD5); also elsewhere on the board
D14~: IC2.15 ((PCINT30/OC2B/ICP)PD6); also elsewhere on the board
D15~: IC2.16 ((PCINT31/OC2A)PD7); also elsewhere on the board
D20: IC2.23 ((PCINT20/TDO)PC4)
D22: IC2.25 ((PCINT22/TOSC1)PC6)
DTR: C43.2; also elsewhere on the board
EXT_3.3V: RTC1.2 (VCC); also elsewhere on the board
GND: ADECOUP.2, C7.2, C41.2, C42.2, CLOCK_BATT.GND (-), IC2.6 (GND), IC2.18 (GND), IC2.28 (GND), IC2.39 (GND), IC2.TH (EXP), LED3.C, R19.2, RTC1.5 (GND), S1.P$3 (3), S1.P$4 (4), SD.3 (VSS1), SD.6 (VSS2), SD.GP (GND), SD.GP3 (COMMON_SW), U$4.P$1 (1), U$4.P$2 (2); also elsewhere on the board
LED+1: LED3.A, R_LED1.2
MANUAL_LOG: D1.2 (A2), IC2.26 ((PCINT23/TOSC2)PC7)
MCU_ADC0: IC2.37 ((PCINT0/ADC0)PA0); also elsewhere on the board
MCU_ADC1: IC2.36 ((PCINT1/ADC1)PA1)
MCU_ADC4: IC2.33 ((PCINT4/ADC4)PA4)
MCU_ADC5: IC2.32 ((PCINT5/ADC5)PA5)
MCU_ADC6: IC2.31 ((PCINT6/ADC6)PA6)
MISO/D6: IC2.2 ((PCINT14/MISO)PB6), SD.7 (DATA_OUT); also elsewhere on the board
MOSI/D5: IC2.1 ((PCINT13/MOSI)PB5), SD.2 (DATA_IN); also elsewhere on the board
unnamed: IC2.40 ((PCINT8/XCK0/T0)PB0), R_LED1.1
unnamed: C7.1, CLOCK_BATT.POWER0 (+), CLOCK_BATT.POWER1 (+), RTC1.6 (VBAT)
unnamed: D1.3 (K), S1.P$1 (1), S1.P$2 (2)
PSYNC: IC2.41 ((PCINT9/CLKO/T1)PB1); also elsewhere on the board
RST: C43.1, IC2.4 (RESET), R1.1, U$4.P$3 (3), U$4.P$4 (4); also elsewhere on the board
RTC_INT: D1.1 (A1), IC2.42 ((PCINT10/INT2/AIN0)PB2), RTC1.3 (SQW)
RX/INT0: IC2.11 ((PCINT26/INT0)PD2); also elsewhere on the board
RX_USB: IC2.9 ((PCINT24/RXD0)PD0); also elsewhere on the board
SCK/D7: IC2.3 ((PCINT15/SCK)PB7), SD.5 (SCLK); also elsewhere on the board
SCL: IC2.19 ((PCINT16/SCL)PC0), RTC1.8 (SCL); also elsewhere on the board
SDA: IC2.20 ((PCINT17/SDA)PC1), RTC1.7 (SDA); also elsewhere on the board
SD_CS: IC2.24 ((PCINT21/TDI)PC5), SD.1 (CS)
SD_VCC: SD.4 (VDD); also elsewhere on the board
SD_VCC_CTRL: IC2.21 ((PCINT18/TCK)PC2); also elsewhere on the board
SS/D4: IC2.44 ((PCINT12/OC0B/!SS!)PB4); also elsewhere on the board
TX/INT1: IC2.12 ((PCINT27/INT1)PD3); also elsewhere on the board
TX_USB: IC2.10 ((PCINT25/TXD0)PD1); also elsewhere on the board
XTAL1: C42.1, IC2.8 (XTAL1), Q3.1
XTAL2: C41.1, IC2.7 (XTAL2), Q3.2

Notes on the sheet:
Log Switch
Pin change int or external level int can both wake up logger from power down. But toggle pin must remain in its toggled state until device has woken up to geterate the interrupt.
Interrupt on RTC grounds the interrupt pin, otherwise the pin is floating and needs an external pullup.

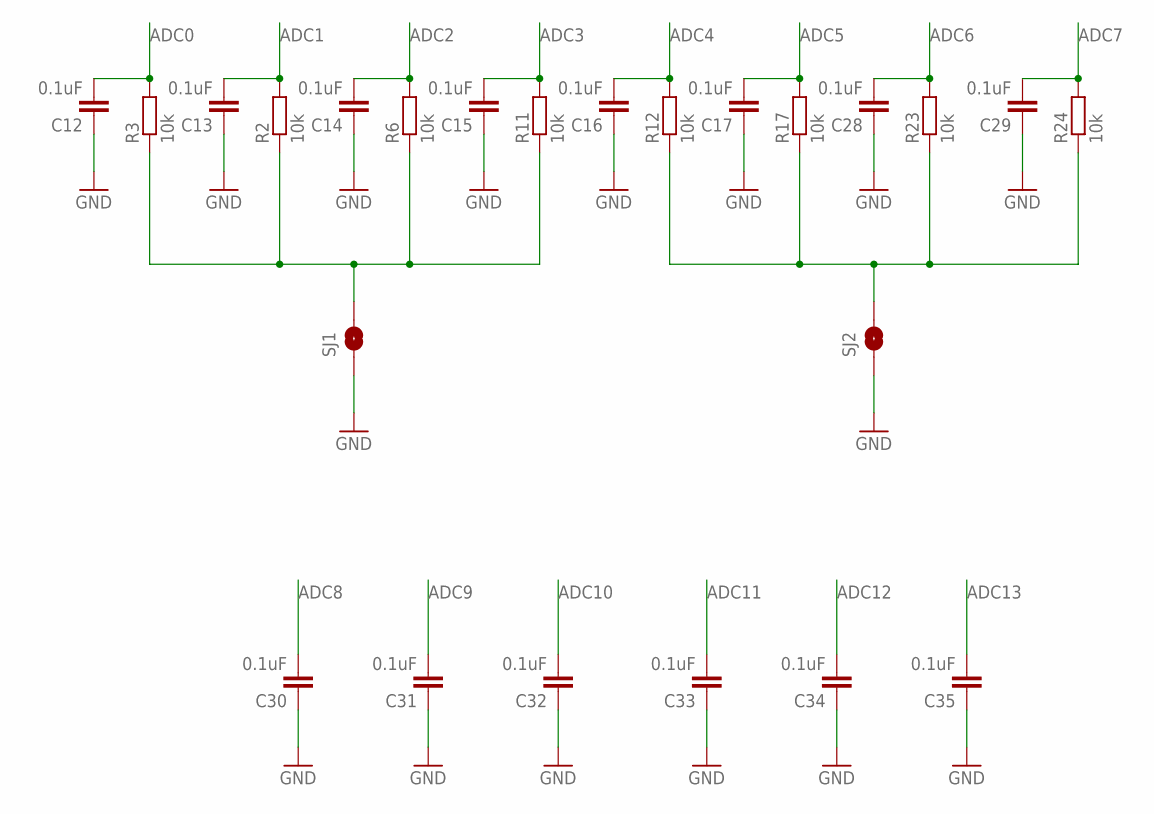
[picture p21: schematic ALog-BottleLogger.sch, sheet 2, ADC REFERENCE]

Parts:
C12, C13, C14, C15, C16, C17, C28, C29, C30, C31, C32, C33, C34, C35: 0.1uF; C0603
R2, R3, R6, R11, R12, R17, R23, R24: 10k; R0603
SJ1, SJ2: SOLDERJUMPER-OLDTRACE; SJ_2S-TRACE

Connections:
ADC0: C12.2, R3.2; also elsewhere on the board
ADC1: C13.2, R2.2; also elsewhere on the board
ADC2: C14.2, R6.2; also elsewhere on the board
ADC3: C15.2, R11.2; also elsewhere on the board
ADC4: C16.2, R12.2; also elsewhere on the board
ADC5: C17.2, R17.2; also elsewhere on the board
ADC6: C28.2, R23.2; also elsewhere on the board
ADC7: C29.2, R24.2; also elsewhere on the board
ADC8: C30.2; also elsewhere on the board
ADC9: C31.2; also elsewhere on the board
ADC10: C32.2; also elsewhere on the board
ADC11: C33.2; also elsewhere on the board
ADC12: C34.2; also elsewhere on the board
ADC13: C35.2; also elsewhere on the board
GND: C12.1, C13.1, C14.1, C15.1, C16.1, C17.1, C28.1, C29.1, C30.1, C31.1, C32.1, C33.1, C34.1, C35.1, SJ1.1, SJ2.1; also elsewhere on the board
unnamed: R12.1, R17.1, R23.1, R24.1, SJ2.2
unnamed: R2.1, R3.1, R6.1, R11.1, SJ1.2

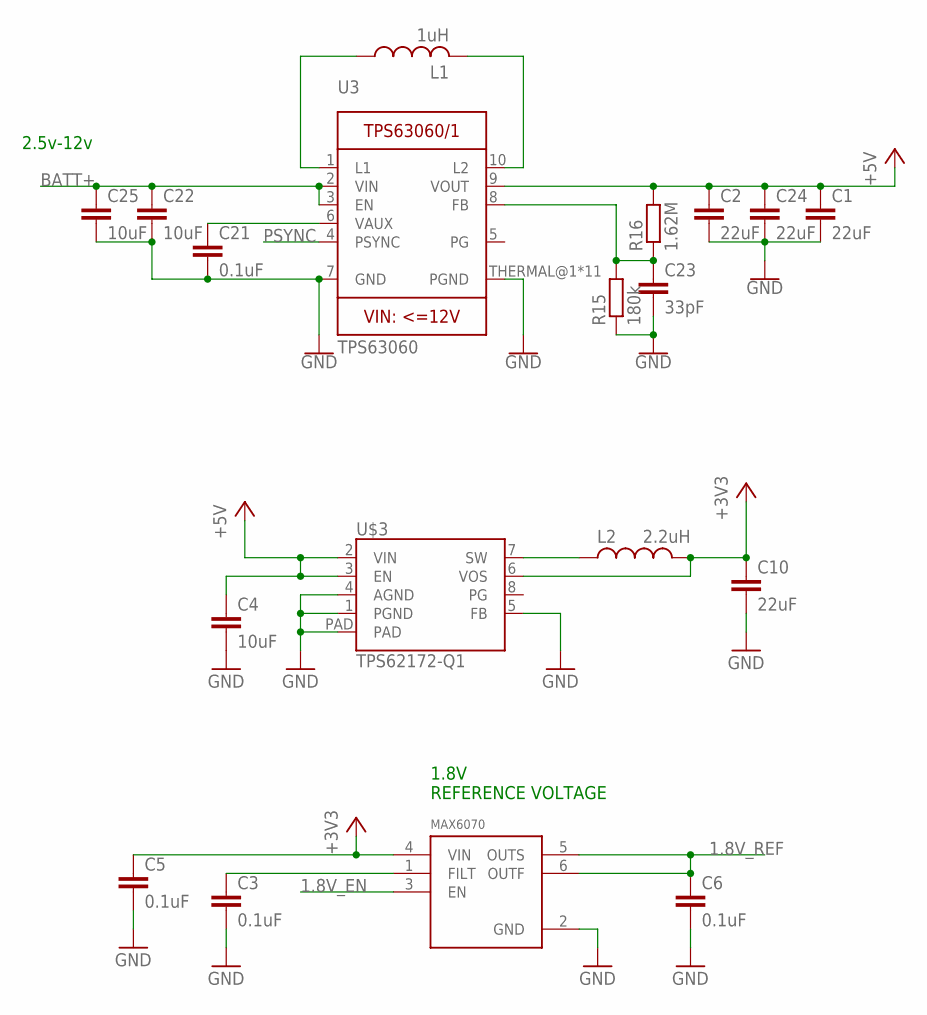
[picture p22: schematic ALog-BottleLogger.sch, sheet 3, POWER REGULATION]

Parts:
C1, C2, C10, C24: 22uF; C0805
C3, C5, C6, C21: 0.1uF; C0603
C4, C22, C25: 10uF; C0805
C23: 33pF; C0603
L1: 1uH; WE-MAIA(4.1X4.1)
L2: 2.2uH; 0806
R15: 180k; R0603
R16: 1.62M; R0603
U3: TPS63060; PWSON-N10
U$2: MAX6070AAUT18; SOT23-6L
U$3: TPS62172-Q1; WSON-8-PAD

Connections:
1.8V_EN: U$2.3 (EN); also elsewhere on the board
1.8V_REF: C6.1, U$2.5 (OUTS), U$2.6 (OUTF); also elsewhere on the board
+3V3: C5.1, C10.1, L2.P$2 (2), U$2.4 (VIN), U$3.6 (VOS); also elsewhere on the board
+5V: C1.1, C2.1, C4.1, C24.1, R16.2, U3.9 (VOUT), U$3.2 (VIN), U$3.3 (EN); also elsewhere on the board
BATT+: C22.1, C25.1, U3.2 (VIN), U3.3 (EN); also elsewhere on the board
GND: C1.2, C2.2, C3.2, C4.2, C5.2, C6.2, C10.2, C21.2, C22.2, C23.2, C24.2, C25.2, R15.1, U3.7 (GND), U3.THERMAL@1 (PGND), U3.THERMAL@5 (PGND), U3.THERMAL@6 (PGND), U3.THERMAL@7 (PGND), U3.THERMAL@8 (PGND), U3.THERMAL@9 (PGND), U3.THERMAL@10 (PGND), U3.THERMAL@11 (PGND), U3.THERMAL@12 (PGND), U3.THERMAL@13 (PGND), U3.THERMAL@14 (PGND), U$2.2 (GND), U$3.1 (PGND), U$3.4 (AGND), U$3.5 (FB), U$3.PAD; also elsewhere on the board
unnamed: L2.P$1 (1), U$3.7 (SW)
unnamed: C21.1, U3.6 (VAUX)
unnamed: C23.1, R15.2, R16.1, U3.8 (FB)
unnamed: L1.P$1 (1), U3.1 (L1)
unnamed: L1.P$2 (2), U3.10 (L2)
unnamed: C3.1, U$2.1 (FILT)
PSYNC: U3.4 (PSYNC); also elsewhere on the board

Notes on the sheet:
2.5v-12v
1.8V REFERENCE VOLTAGE

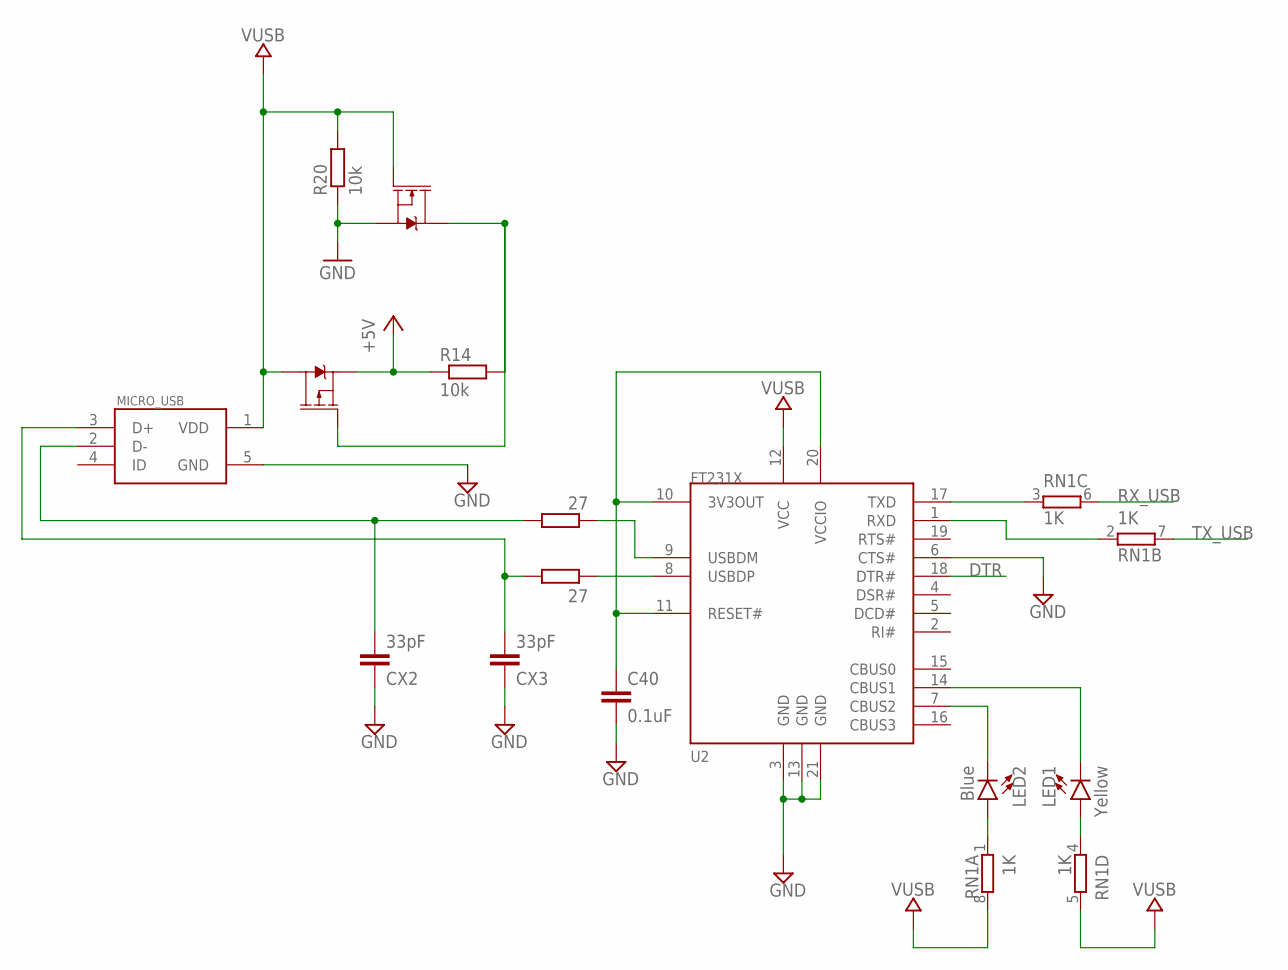
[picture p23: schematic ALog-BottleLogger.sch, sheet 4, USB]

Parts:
C40: 0.1uF; C0603
CX2, CX3: 33pF; C0603
D+: 27; R0603
D-: 27; R0603
LED1: Yellow; LED-0603
LED2: Blue; LED-0603
MICRO_USB: MICRO_USB_LONGPADS; 10118194-0001LF_10118194-0001LF_LONGER_PADS
Q11: 310mA/60V/1.6Ω; SOT323
Q12: FDN360P; SOT23-3
R14, R20: 10k; R0603
RN1: 1K; 0603-ARC
U2: FT231X-Q; QFN20

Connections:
+5V: Q12.2 (S), R14.1; also elsewhere on the board
DTR: U2.18 (DTR#); also elsewhere on the board
GND: C40.2, CX2.1, CX3.1, MICRO_USB.5 (GND), Q11.2 (S), R20.1, U2.3 (GND), U2.6 (CTS#), U2.13 (GND), U2.21 (GND); also elsewhere on the board
unnamed: LED2.A, RN1.1
unnamed: LED1.A, RN1.4 (1)
unnamed: RN1.3 (1), U2.17 (TXD)
unnamed: Q11.3 (D), Q12.1 (G), R14.2
unnamed: CX3.2, D+.2, MICRO_USB.3 (D+)
unnamed: CX2.2, D-.2, MICRO_USB.2 (D-)
unnamed: D+.1, U2.8 (USBDP)
unnamed: RN1.2 (1), U2.1 (RXD)
unnamed: C40.1, U2.10 (3V3OUT), U2.11 (RESET#), U2.20 (VCCIO)
unnamed: LED2.C, U2.7 (CBUS2)
unnamed: LED1.C, U2.14 (CBUS1)
unnamed: D-.1, U2.9 (USBDM)
RX_USB: RN1.6 (2); also elsewhere on the board
TX_USB: RN1.7 (2); also elsewhere on the board
VUSB: MICRO_USB.1 (VDD), Q11.1 (G), Q12.3 (D), R20.2, RN1.5 (2), RN1.8 (2), U2.12 (VCC)

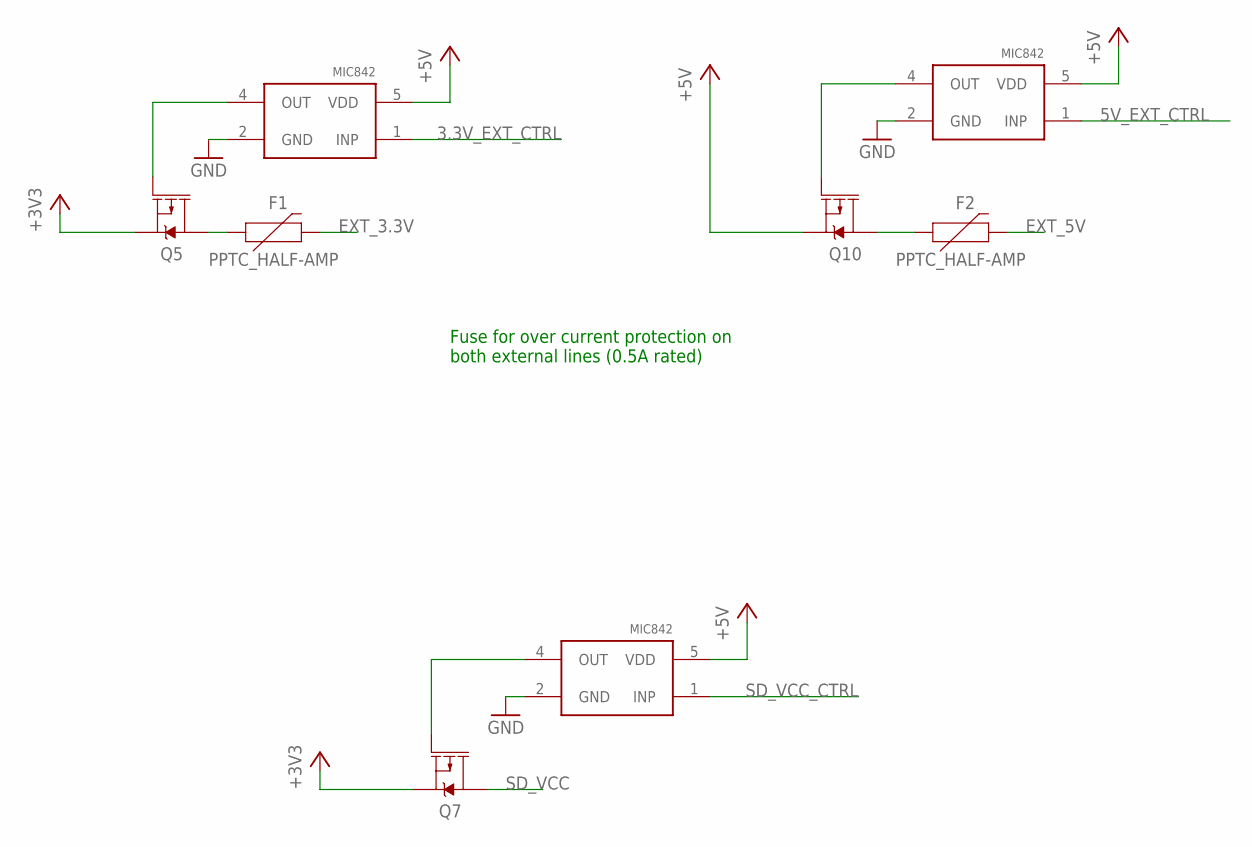
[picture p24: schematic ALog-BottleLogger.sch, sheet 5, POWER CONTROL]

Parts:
F1, F2: PPTC_HALF-AMP; 1206
Q5, Q7, Q10: FDN360P; SOT23-3
U$1, U$12, U$16: MIC842; DCK_R-PDSO-G5

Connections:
3.3V_EXT_CTRL: U$12.1 (INP); also elsewhere on the board
5V_EXT_CTRL: U$1.1 (INP); also elsewhere on the board
+3V3: Q5.2 (S), Q7.2 (S); also elsewhere on the board
+5V: Q10.2 (S), U$1.5 (VDD), U$12.5 (VDD), U$16.5 (VDD); also elsewhere on the board
EXT_3.3V: F1.2; also elsewhere on the board
EXT_5V: F2.2; also elsewhere on the board
GND: U$1.2 (GND), U$12.2 (GND), U$16.2 (GND); also elsewhere on the board
unnamed: Q5.1 (G), U$12.4 (OUT)
unnamed: Q10.1 (G), U$1.4 (OUT)
unnamed: F1.1, Q5.3 (D)
unnamed: Q7.1 (G), U$16.4 (OUT)
unnamed: F2.1, Q10.3 (D)
SD_VCC: Q7.3 (D); also elsewhere on the board
SD_VCC_CTRL: U$16.1 (INP); also elsewhere on the board

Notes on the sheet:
Fuse for over current protection on both external lines (0.5A rated)

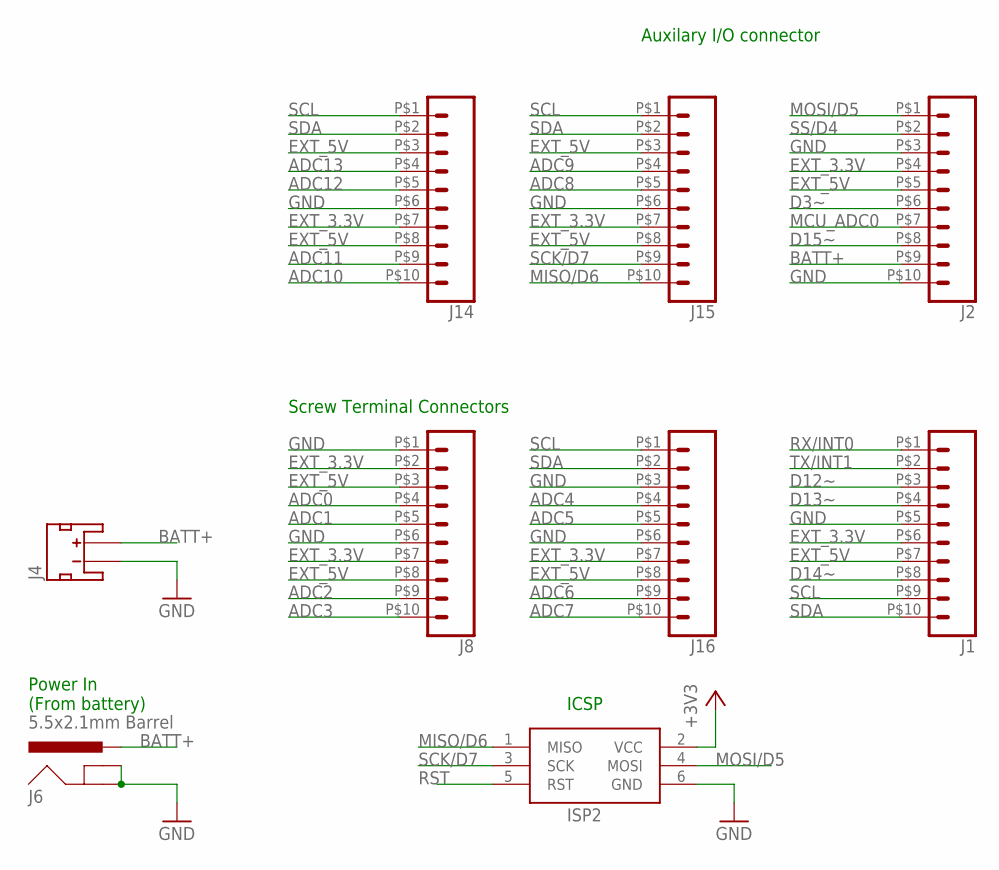
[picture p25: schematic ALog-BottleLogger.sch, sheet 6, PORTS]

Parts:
ISP2: AVRISP-6; AVRISP
J1, J2, J8, J14, J15, J16: CONN_103.5MM; 1X10_3.5MM_SCREW
J4: JST_2MM_MALE; JST-2-SMD
J6: 5.5x2.1mm Barrel; POWER_JACK_SMD

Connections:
+3V3: ISP2.2 (VCC); also elsewhere on the board
ADC0: J8.P$4 (4); also elsewhere on the board
ADC1: J8.P$5 (5); also elsewhere on the board
ADC2: J8.P$9 (9); also elsewhere on the board
ADC3: J8.P$10 (10); also elsewhere on the board
ADC4: J16.P$4 (4); also elsewhere on the board
ADC5: J16.P$5 (5); also elsewhere on the board
ADC6: J16.P$9 (9); also elsewhere on the board
ADC7: J16.P$10 (10); also elsewhere on the board
ADC8: J15.P$5 (5); also elsewhere on the board
ADC9: J15.P$4 (4); also elsewhere on the board
ADC10: J14.P$10 (10); also elsewhere on the board
ADC11: J14.P$9 (9); also elsewhere on the board
ADC12: J14.P$5 (5); also elsewhere on the board
ADC13: J14.P$4 (4); also elsewhere on the board
BATT+: J2.P$9 (9), J4.2 (+), J6.VIN0 (PWR); also elsewhere on the board
D3~: J2.P$6 (6); also elsewhere on the board
D12~: J1.P$3 (3); also elsewhere on the board
D13~: J1.P$4 (4); also elsewhere on the board
D14~: J1.P$8 (8); also elsewhere on the board
D15~: J2.P$8 (8); also elsewhere on the board
EXT_3.3V: J1.P$6 (6), J2.P$4 (4), J8.P$2 (2), J8.P$7 (7), J14.P$7 (7), J15.P$7 (7), J16.P$7 (7); also elsewhere on the board
EXT_5V: J1.P$7 (7), J2.P$5 (5), J8.P$3 (3), J8.P$8 (8), J14.P$3 (3), J14.P$8 (8), J15.P$3 (3), J15.P$8 (8), J16.P$8 (8); also elsewhere on the board
GND: ISP2.6 (GND), J1.P$5 (5), J2.P$3 (3), J2.P$10 (10), J4.1 (-), J6.GND (GNDBREAK), J6.P$4 (GND), J8.P$1 (1), J8.P$6 (6), J14.P$6 (6), J15.P$6 (6), J16.P$3 (3), J16.P$6 (6); also elsewhere on the board
MCU_ADC0: J2.P$7 (7); also elsewhere on the board
MISO/D6: ISP2.1 (MISO), J15.P$10 (10); also elsewhere on the board
MOSI/D5: ISP2.4 (MOSI), J2.P$1 (1); also elsewhere on the board
RST: ISP2.5 (RST); also elsewhere on the board
RX/INT0: J1.P$1 (1); also elsewhere on the board
SCK/D7: ISP2.3 (SCK), J15.P$9 (9); also elsewhere on the board
SCL: J1.P$9 (9), J14.P$1 (1), J15.P$1 (1), J16.P$1 (1); also elsewhere on the board
SDA: J1.P$10 (10), J14.P$2 (2), J15.P$2 (2), J16.P$2 (2); also elsewhere on the board
SS/D4: J2.P$2 (2); also elsewhere on the board
TX/INT1: J1.P$2 (2); also elsewhere on the board

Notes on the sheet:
Screw Terminal Connectors
ICSP
Auxilary I/O connector
Power In (From battery)

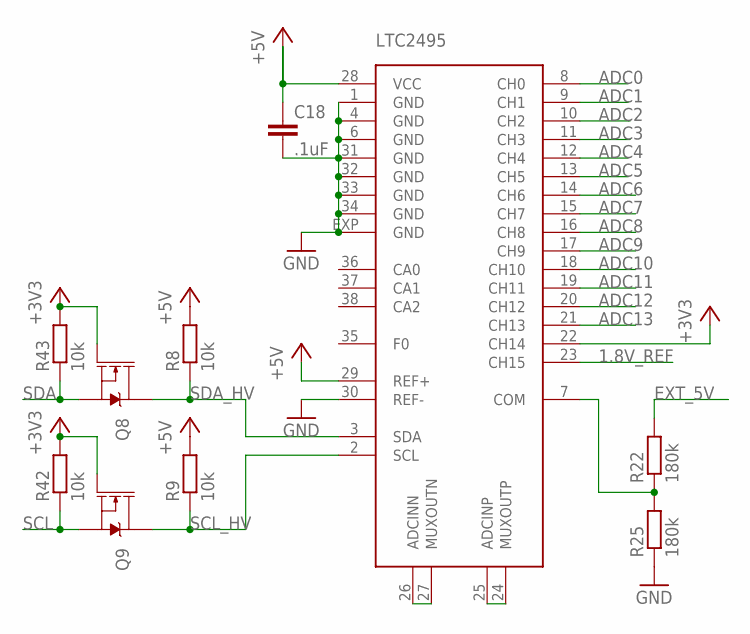
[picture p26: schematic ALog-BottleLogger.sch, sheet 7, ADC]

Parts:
C18: .1uF; C0603
Q8: 310mA/60V/1.6Ω; SOT323
Q9: 2N7002; SOT323
R8, R9, R42, R43: 10k; R0603
R22: 180k; R0603
R25: 180k; R0603; MPN AC0603FR-07180KL; DIGIKEY 311-180KLDCT-ND
U$7: LTC2495; QFN38-5X7

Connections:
1.8V_REF: U$7.23 (CH15); also elsewhere on the board
+3V3: Q8.1 (G), Q9.1 (G), R42.2, R43.2, U$7.22 (CH14); also elsewhere on the board
+5V: C18.1, R8.2, R9.2, U$7.28 (VCC), U$7.29 (REF+); also elsewhere on the board
ADC0: U$7.8 (CH0); also elsewhere on the board
ADC1: U$7.9 (CH1); also elsewhere on the board
ADC2: U$7.10 (CH2); also elsewhere on the board
ADC3: U$7.11 (CH3); also elsewhere on the board
ADC4: U$7.12 (CH4); also elsewhere on the board
ADC5: U$7.13 (CH5); also elsewhere on the board
ADC6: U$7.14 (CH6); also elsewhere on the board
ADC7: U$7.15 (CH7); also elsewhere on the board
ADC8: U$7.16 (CH8); also elsewhere on the board
ADC9: U$7.17 (CH9); also elsewhere on the board
ADC10: U$7.18 (CH10); also elsewhere on the board
ADC11: U$7.19 (CH11); also elsewhere on the board
ADC12: U$7.20 (CH12); also elsewhere on the board
ADC13: U$7.21 (CH13); also elsewhere on the board
EXT_5V: R22.2; also elsewhere on the board
GND: C18.2, R25.1, U$7.1 (GND), U$7.4 (GND), U$7.6 (GND), U$7.30 (REF-), U$7.31 (GND), U$7.32 (GND), U$7.33 (GND), U$7.34 (GND), U$7.EXP (GND); also elsewhere on the board
unnamed: R22.1, R25.2, U$7.7 (COM)
unnamed: U$7.24 (MUXOUTP), U$7.25 (ADCINP)
unnamed: U$7.26 (ADCINN), U$7.27 (MUXOUTN)
SCL: Q9.2 (S), R42.1; also elsewhere on the board
SCL_HV: Q9.3 (D), R9.1, U$7.2 (SCL)
SDA: Q8.2 (S), R43.1; also elsewhere on the board
SDA_HV: Q8.3 (D), R8.1, U$7.3 (SDA)

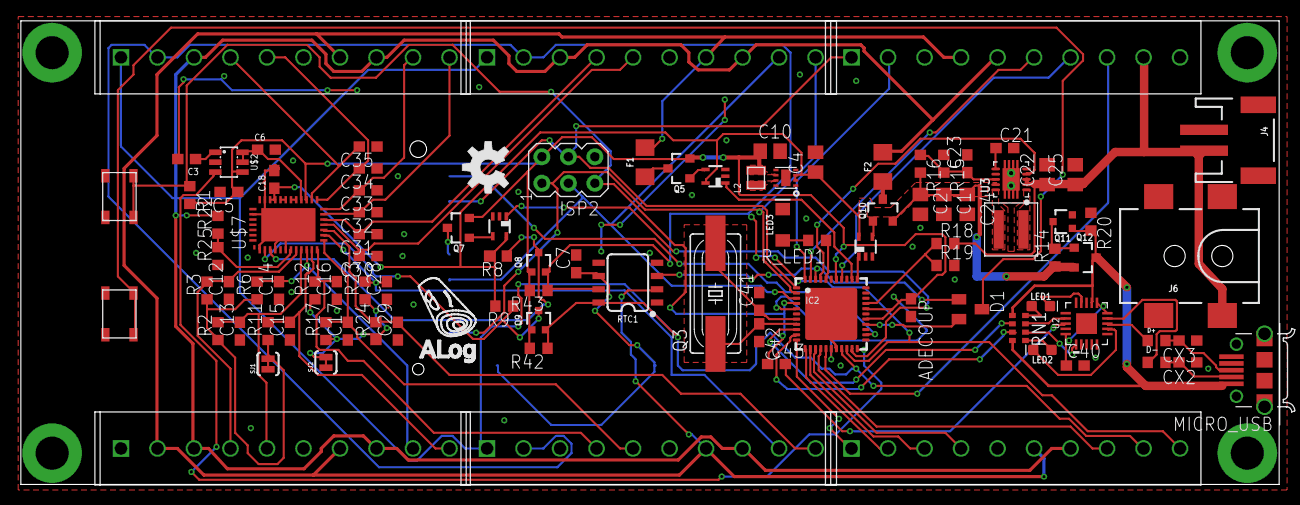
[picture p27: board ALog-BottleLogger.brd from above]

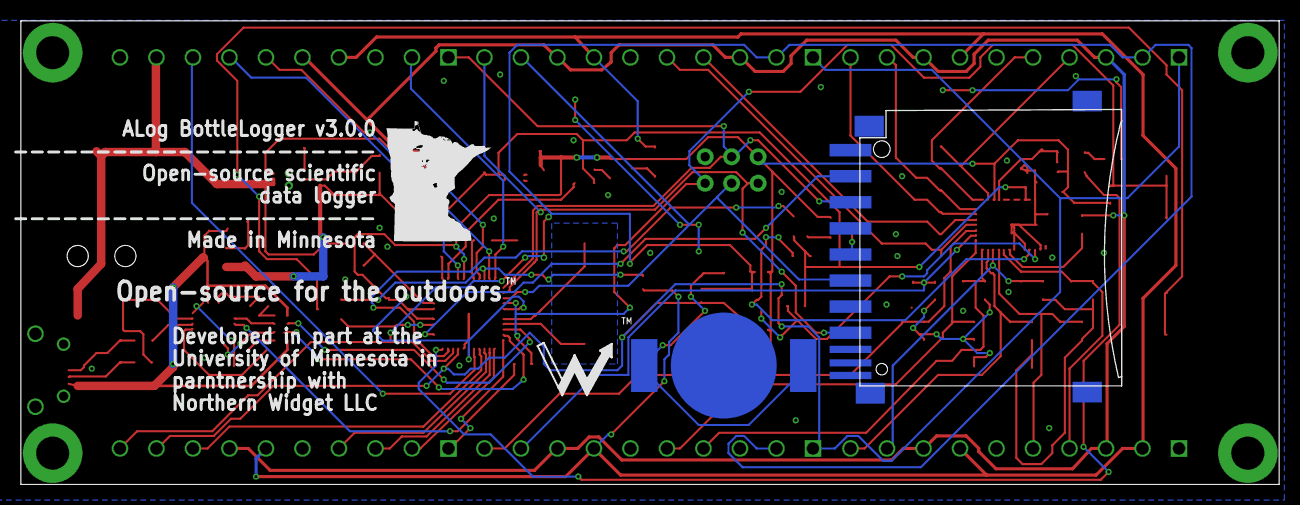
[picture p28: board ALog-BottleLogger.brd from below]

Board: 2 copper layers, 120.7 x 44.5 mm, 106 parts (3 on the bottom side), 86 nets.

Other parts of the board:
LOGO2: OSHW-LOGOM; OSHW-LOGO-M
U$13: MN_SILK
U$14: ALOG_LOGO_V1_5.5MM; ALOG_LOGO_V1_SMALL
U$15: NWLOGO_MED

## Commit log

2013-09-11 Adding version 1.0.0 files to the master branch
    [ALog_BottleLogger_100_bill_of_materials.csv, ALog_BottleLogger_100_bill_of_materials.xls, ALog_BottleLogger_100_bill_of_materials_replacement_resistor_in_stock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]
2016-04-27 Next generation: breaking out more pins
    [logger.brd, logger.sch]
2016-04-27 exposed interfaces, button update, board layout
    (1) Exposed SPI, I2C, and UART interfaces
    (2) Added 1K resistors to UART to allow switching away from the computer
    (3) Updated the buttons to PTH (higher button: RESET), PTH DPDT b/c of
    availability (LOG NOW)
    (4) Reworked the board layout to keep the same form factor while adding
    many new screw terminals (and keeping the 3.5 mm spacing)
    [logger.brd, logger.sch]
2016-04-27 10nF chip caps for analog, following Gerhard Oberforcher
    [logger.brd, logger.sch]
2016-04-27 a big mess of getting a new FTDI chip
    [logger.brd, logger.sch]
2016-04-28 Added diode OR, not connected yet
    [logger.brd, logger.sch]
2016-04-28 New FTDI chip, power-saving clock circuits (h/t Gerhard), with Chad Sandell
    [logger.brd, logger.sch]
2016-04-28 routed board with clock power-save and new FTDI
    [logger.brd, logger.sch]
2016-04-28 Uniform MOSFETs; diode connection fix
    [logger.brd, logger.sch]
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2016-04-29 Improved board, modified and consolidated some components
    [logger.brd, logger.sch]
2016-04-29 Rmv via at screw hole
    [logger.brd, logger.sch]
2016-04-29 Final BoM for ALog 1.1 order
    [ALog_BottleLogger_bill_of_materials.csv, ALog_BottleLogger_bill_of_materials.xls]
2016-05-07 Return to classic FTDI USB/serial
    [logger.brd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]
2016-05-07 Keep a live version of Logger 1.1.0 (new FTDI)
    [logger110.brd, logger110.sch]
2016-05-17 can not get this to autoroute
    [logger_Chad.brd, logger_Chad.sch]
2016-05-17 Routed board, ground fills and minimized timing device distances
    [logger_Chad.brd, logger_Chad.sch]
2016-05-18 replace logger with logger_Chad
    [logger.brd, logger.sch]
2016-05-18 remove logger_Chad files, changed to logger
    [logger_Chad.brd, logger_Chad.sch]
2016-05-20 Added 5V boost from VCC to board
    [ALog_BottleLogger_bill_of_materials.xls, logger.brd, logger.sch]
2016-05-24 Route EN pin to tie into 3.3V digital pin (D6 I think)
    [logger.brd, logger.sch]
2016-05-25 5V pin on both sides of board instead of duel ground pins on one side
    [logger.brd, logger.sch]
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2016-07-28 Updated BOM and board layout with cheaper and smaller component packages
    [ALog_BottleLogger_BOM_JUL222016.xls, ALog_BottleLogger_bill_of_materials.csv, logger.brd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]
2016-08-01 33pF decoupling on USB data; Rx Tx LED flip
    [logger.brd, logger.sch]
2016-08-09 Fixed misrouted trace
    [logger.brd]
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2016-08-31 Latest design files and board lable fix
    [ALog_BottleLogger_bill_of_materials.xls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]
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2016-10-06 Added JST connector option to logger, started 2G communication
    [ALog_BottleLogger_bill_of_materials.xls, loggerV3.0.brd, loggerV3.0.sch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]
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2016-10-28 change 3V3 power supply with jumpers, routing needs finishing
    [ALog_BottleLogger_bill_of_materials.xls, logger.brd, logger.sch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]
2016-10-29 Routed and ready for Wickert check of approval
    [logger.brd, logger.sch]
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2016-10-30 Rerouted with VDD linked to RTC and SD; updated silk labels
    [logger.brd]
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2016-10-31 BOM updates from change to duel 3.3V regulator
    [ALog_BottleLogger_bill_of_materials.xls]
2016-10-31 removed via under ground pad and fixed 1 airwire
    [logger.brd]
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2016-12-20 4412 routing fix and silkscreen gerber fix
    [logger.brd, logger.sch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]
2016-12-29 Fix device usage column
    [ALog_BottleLogger_bill_of_materials.xls]
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2016-12-30 fixed Miso Mosi Silk Screen labels
    [logger.brd]
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2017-01-09 Create custom pads for 3V3 output voltage chip
    [logger.brd, logger.sch]
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2017-01-30 Switch pins to PWM; need to update software!
    [logger.brd, logger.sch]
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2017-02-04 Smaller back silk -- doesn't overlap through-hole components
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2017-03-01 Moved 4050 up to increase label visibility, work in progress
    [logger.brd]
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2017-03-08 Simplify I2C pull-ups: no more shorts
    [logger.brd]
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2017-03-11 SMD LED and Crystal, with I2C pullup short fix
    [logger.brd]
2017-03-11 Silk date update, Route GND, DRC and clearance
    [logger.brd]
2017-03-19 changed pads on capacitor array's, ready for prime time? Check crystal pad.
    [logger.brd]
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2017-03-21 Fix logger board outline
    [logger.brd]
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2017-03-23 SMD USB (micro-B), barrel jack, and battery holder; tentative SMD 1x6 header blocks
    [logger.brd]
2017-03-23 Barrel jack not protruding from board, and fully re-routed
    [logger.brd]
2017-03-31 MOSFET level shifter for SPI, parts for I2C
    [logger.brd]
2017-03-31 All airwires routed; parts for I2C level shifter remain
    [logger.brd]
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2017-04-01 Restore SDA and SCL level shifter; 3V3 output from board
    [logger.brd]
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2017-04-07 through hole and surface mount design in progress
    [logger.brd]
2017-04-10 Surface mount reference resistor sockets need to be centered, removing for now
    [logger.brd]
2017-04-10 Removed Surface mount ref resistor headers and changed USB connector
    [logger.brd]
2017-04-10 Updated silk; updates to 'awickert.lbr' messed up voltage switcher
    [logger.brd]
2017-04-10 Fixed accedental change to 4412 chip
    [logger.brd]
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2017-06-06 Naming consistency with other boards: no longer the only "logger"!
    [ALog-BottleLogger.brd]
2017-07-01 ALog logo on back silk; no Northern Widget
    [ALog-BottleLogger.brd]
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2017-08-24 4.75 inches long, reference voltages broken out
    [ALog-BottleLogger.brd, ALog-BottleLogger.sch]
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2017-08-24 Add 10K pull downs on mosphets for external controls
    [ALog-BottleLogger.brd, ALog-BottleLogger.sch]
2017-08-30 Fixed 5V control and a few other things, fully routed and ready for review
    [ALog-BottleLogger.brd, ALog-BottleLogger.sch]
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2017-09-21 Changed cap sizes on 10 and 22 uF to 805 and fixed MISO/MOSI labels on SD card.
    [ALog-BottleLogger.brd, ALog-BottleLogger.sch]
2017-09-27 Corrected footprint of 5V regulator
    [ALog-BottleLogger.brd, ALog-BottleLogger.sch]
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2017-10-03 latest gerber files, fixes to traces, change to power regulators
    [ALog-BottleLogger.GBL, ALog-BottleLogger.GBS, ALog-BottleLogger.GTL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]
2017-10-06 Fixed USB FTDI mosphet connections, updated 3.3V regulator, fixed ground connection on 1.8V reg
    [ALog-BottleLogger.brd, ALog-BottleLogger.sch]
2017-10-06 Moved via that blocked 3v3 pin 1 label
    [ALog-BottleLogger.brd]
2017-10-06 Need to fix DTR connection and remove or isolate ground plane under crystal
    [ALog-BottleLogger.brd, ALog-BottleLogger.sch]
2017-10-10 Routed DTR and removed fill planes from under crystal
    [ALog-BottleLogger.brd]
2017-10-23 COM on ADC should be 2.5V divided from 5V not GND
    [ALog-BottleLogger.brd, ALog-BottleLogger.sch]
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2017-11-04 Final revisions made, many changes, 5V external mosphet update, RTC power configuration, add 5V psync control pin, change external power control pins, add barrel jack, rerouted whole board
    [ALog-BottleLogger.brd, ALog-BottleLogger.sch]
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2017-11-07 Minor trace fixes, back silkscreen info additions
    [ALog-BottleLogger.brd]
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2017-12-20 Added comparators, added SCL/SDA connections, updated resistor values and voltage divider sources
    [ALog-BottleLogger.brd, ALog-BottleLogger.sch]
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2017-12-28 Add comparators for power control, change header layout adding more I2C, change clock power supply
    [ALog-BottleLogger.brd, ALog-BottleLogger.sch]
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2018-09-14 Cleanup and PDF creation
    Cleaned up and updated old parts, added frames to schematic, printed schematic to PDF
    [ALog-BottleLogger.brd, ALog-BottleLogger.sch]
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

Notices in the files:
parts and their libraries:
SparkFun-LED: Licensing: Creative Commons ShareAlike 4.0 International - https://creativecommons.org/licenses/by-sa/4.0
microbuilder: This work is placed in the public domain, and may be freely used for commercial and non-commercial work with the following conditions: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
